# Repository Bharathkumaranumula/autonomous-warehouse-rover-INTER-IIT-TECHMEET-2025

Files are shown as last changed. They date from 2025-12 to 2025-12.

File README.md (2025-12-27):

# Autonomous Rover for Warehouse Rack Inventory Management

## About the Project
This project was developed as part of **Inter IIT Tech Meet 14.0** under the problem statement **“Autonomous Rover for Warehouse Rack Inventory Management.”**  
The objective was to design and build an autonomous wheeled robot capable of navigating warehouse aisles and performing **reliable vertical inventory scanning up to 2 meters**.

The system aims to replace slow, unsafe, and error-prone manual inventory audits with a compact, accurate, and scalable robotic solution suitable for modern warehouse environments.

---

## My Contribution
I was responsible for the **entire hardware design and implementation** of this project. My role covered the complete hardware lifecycle, including mechanical design, structural layout, drive system selection, Z-axis scissor lift design, power system architecture, safety mechanisms, and hardware integration.

I led the hardware development from problem understanding and calculations through CAD design, fabrication, assembly, and testing, ensuring the system met competition constraints and performed reliably during integrated operation.

---

## Problem Statement Summary
Modern warehouses face several challenges:
- Manual inventory audits take **10–15 minutes per rack**
- Human errors lead to **30–50% stock mismatches**
- Ladder-based high-rack inspections are unsafe
- Inventory data lacks real-time visibility

The robot must:
- Navigate narrow warehouse aisles autonomously
- Detect and align with storage racks
- Perform vertical scanning across multiple shelf levels (up to ~2 m)
- Reliably capture QR-based inventory data
- Operate safely within strict size and weight constraints

---

## Proposed Solution
The solution is a **compact autonomous differential-drive rover** equipped with a **centrally mounted multi-stage scissor lift** for vertical scanning.

Key system capabilities include:
- Autonomous indoor navigation
- Vertical scanning up to ~1.8–2.0 m
- High QR scanning accuracy
- Modular mechanical and electrical design
- Robust safety and fail-safe mechanisms

---

## System Overview
- Robot type: Autonomous wheeled mobile robot  
- Drive type: Differential drive (2 powered wheels + 2 ball casters)  
- Vertical actuation: Four-stage scissor lift  
- Maximum scanning height: ~1.8–2.0 m  
- Total system mass: ~20 kg  
- Footprint: 570 × 355 mm  
- Compute: NVIDIA Jetson AGX Xavier  
- Low-level control: ESP32  

---

## Hardware Architecture

### 1. Chassis and Structural Design
- Dimensions: **570 × 355 × 145 mm**
- Ground clearance: **25 mm**
- Total mass: **≈ 20 kg**
- Material: **6062 aluminium T-slot profiles (20 × 20 mm)**
- Closed-box frame topology for improved stiffness
- Low and centrally placed mass for anti-tip stability
- Modular mounting surfaces for rapid iteration

---

### 2. Locomotion System (X–Y Motion)
- Drive configuration: **2-wheel differential drive**
- Support: Front and rear metal ball casters
- Turning radius: **0 mm (on-the-spot rotation)**
- Drive wheel diameter: **100 mm**
- Wheel width: **25 mm**
- Motors: **RMCS 2012 DC motors**
  - Voltage: 18 V  
  - Gearbox: 1:25 planetary  
  - Rated torque: 39 kg·cm  
  - Encoders: ~1300 CPR at wheel  
- Direct-drive layout for minimal backlash
- Stability and torque validated with conservative acceleration limits

---

### 3. Z-Axis Scissor Lift Mechanism
- Mechanism: **Four-stage scissor lift**
- Actuation: Horizontally oriented lead screw
- Camera height range: **~320 mm to ~1780 mm**
- Usable vertical coverage: **~1800 mm**
- Shelf levels supported: **5 discrete heights**
- Vertical accuracy target: **±20 mm**
- Achieved repeatability: **~9–18 mm**
- Anti-sway achieved through symmetric geometry and tight-fit bearings
- Mechanical hard stops and limit switches for safety

---

### 4. Power System
- Three independent Li-Po batteries:
  - Jetson AGX Xavier
  - Drive motors
  - Z-axis motor
- 25C discharge capability
- Power Management Unit (PMU) for regulated distribution
- Electrical isolation between compute and motors
- Live battery monitoring and diagnostics

---

### 5. Control Electronics
- Microcontroller: **ESP32 DevKit-V1**
- Motor drivers: **Cytron MDD20A**
- Encoder-based closed-loop PID control
- UART communication between ESP32 and Jetson
- PCB designed with separate logic and power zones for reliability

---

### 6. Safety Systems
- Electronic kill switch (power cut-off)
- Physical emergency stop (E-stop)
- Z-axis limit switches and bump switch
- Firmware-level command clamping
- Software-triggered emergency stop on fault detection

---

## Hardware–Software Integration
- ESP32 handles real-time motor control and encoder feedback
- Jetson AGX Xavier handles perception, mapping, and planning
- ROS2 hardware interfaces synchronize:
  - X–Y motion
  - Z-axis positioning
  - Scanning tasks
- Closed-loop feedback ensures stable and repeatable operation

---

## Testing and Validation
Hardware validation included:
- Static load and structural stability tests
- Drive torque and acceleration verification
- Full-stroke Z-axis endurance testing
- Vertical positioning repeatability tests
- Integrated navigation + lift + scanning runs

### Key Results
- Vertical repeatability: **≤ 18 mm**
- Platform tilt at maximum lift: **≤ 1.3°**
- QR scanning success rate: **96% first pass, 100% with rescan**
- No jamming or over-current events observed

---

## Key Hardware Highlights
- Horizontally actuated scissor lift within base footprint
- Modular T-slot chassis acting as a mechanical backplane
- Differential drive optimized for stability and control simplicity
- COTS-heavy, serviceable, and student-replicable design
- Hardware decisions driven by safety and testability

---

## Documentation
Detailed mechanical design, calculations, CAD models, testing procedures, and validation results are available in the **attached technical report** provided with this repository.

---

## Acknowledgements
Developed as part of **Inter IIT Tech Meet 14.0** under the **Eternal** problem statement on warehouse automation.

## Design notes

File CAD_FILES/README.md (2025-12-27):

# CAD Files Folder

**Project:**Autonomous Rover for Warehouse Rack Inventory Management
**Type:** Robotic Lifting & Mobility System  
**File Format:** STEP (.step)

---

##  Overview

This is a robotic lifting and mobility system designed around a scissor mechanism mounted onto a mobile chassis. The system integrates vertical motion through a Z-axis actuator, real-time sensing through an Intel RealSense D455i camera, and wheel-based locomotion.

This repository contains the STEP files required to view, analyze, or manufacture the mechanical assembly.

---

##  File Structure & Component Manifest

Below is a detailed breakdown of the subsystems and their corresponding CAD files.

### 1. Main Assembly Structure
**File:** `MAIN_BODY.step`
* **Purpose:** The primary chassis and structural base for the complete mechanism.
* **Mounting Position:** Acts as the base foundation. All major components—including the scissor mechanism, drive motors, slider guides, and electronics—interface directly with this part.

### 2. Scissor Mechanism
**Files:** `FIXED_SCISSOR_MOUNTING_BOTTOM.step`
* **Purpose:** Lower mounting base for the scissor mechanism.
* **Mounting Position:** Rigidly attached to the main chassis; holds the bottom hinge points.

**Files:** `SCISSOR_MECHANISM_LINK-1.step` / `SCISSOR_MECHANISM_LINK-2.step`
* **Purpose:** The primary link arms forming the cross-bar structure of the scissor lift.
* **Mounting Position:** Assembled with pivot joints to form the extendable mechanical linkage.

**File:** `SCISSOR_MECHANISM_SLIDER_SLOT.step`
* **Purpose:** Linear guide slot used to guide the motion of the scissor pivot.
* **Mounting Position:** Attached to the chassis or slider platform.

### 3. Slider and Support System
**Files:** `SLIDER_MOUNT_TYPE_1.step` / `SLIDER_MOUNT_TYPE_2.step`
* **Purpose:** Slider support assemblies ensuring smooth linear travel.
* **Mounting Position:** Located along the slider slot and support rails.

### 4. Actuation and Mobility
**File:** `Z_AXIS_ACTUATIOR_MOTOR_MOUNT.step`
* **Purpose:** Motor bracket for the Z-axis actuator (leadscrew or linear actuator).
* **Mounting Position:** Connected to the chassis, aligned with the lift’s thrust axis.

**File:** `WHEEL_MOTOR_SUPPORT_MOUNT.step`
* **Purpose:** Housing mount for the drive motors controlling robot locomotion.
* **Mounting Position:** Located on the lower-side faces of the chassis.

### 5. Sensing and Vision
**File:** `CAMERA_MOUNT.step`
* **Purpose:** Dedicated mount for the **Intel RealSense D455i** depth camera.
* **Mounting Position:** Placed behind the main actuator or rear side of the motor assembly, facing forward. Used for SLAM, mapping, and perception.

---

##  System Summary

| Subsystem | Components | Functional Purpose |
| :--- | :--- | :--- |
| **Chassis** | `MAIN_BODY` | Structural base and interface for all modules |
| **Lifting System** | Links + Slider components | Vertical movement (Scissor Lift) |
| **Actuator** | Z-axis motor mount | Power transmission for lift |
| **Drive** | Wheel motor support mounts | Horizontal mobility |
| **Vision** | Camera mount | Environment perception & navigation |

---

##  Usage
These files are provided in **.STEP** format, which is widely supported by standard CAD software including:
* SolidWorks
* Autodesk Fusion 360
* FreeCAD
* Onshape

To view the full assembly, import `MAIN_BODY.step` first, followed by the sub-components using the mounting positions described above.

---
*Documentation generated for the ETERNAL CAD Project.*

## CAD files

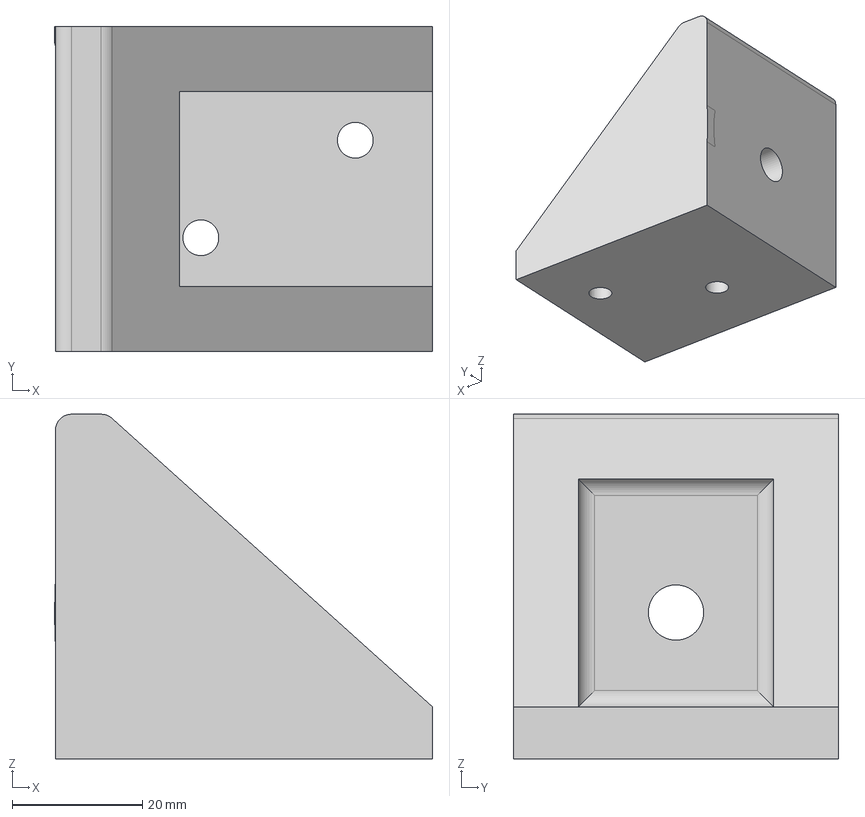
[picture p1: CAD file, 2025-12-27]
CAD_FILES/Z-axis/SLIDER_MOUNT_TYPE_2.step
58.1 x 50.0 x 53.0 mm

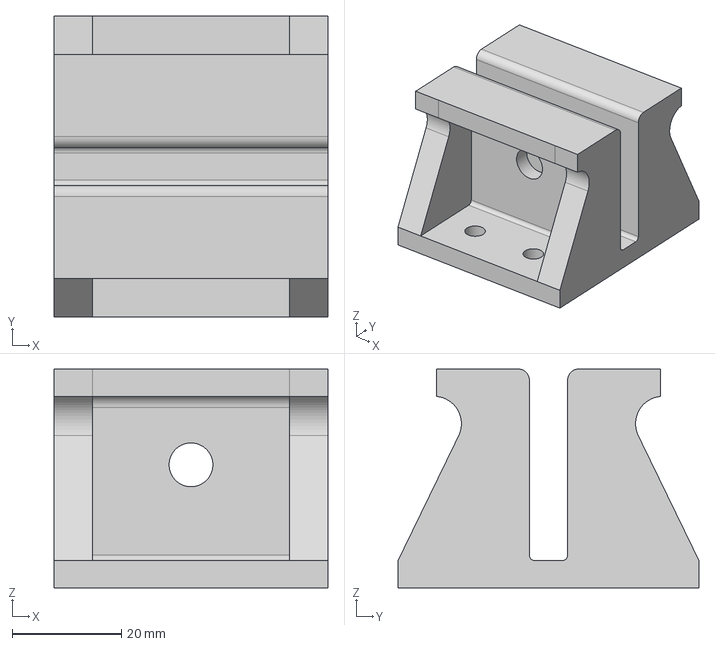
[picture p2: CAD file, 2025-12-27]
CAD_FILES/Z-axis/FIXED_SCISSOR_MOUNTING_BOTTOM.step
50.0 x 55.0 x 40.0 mm

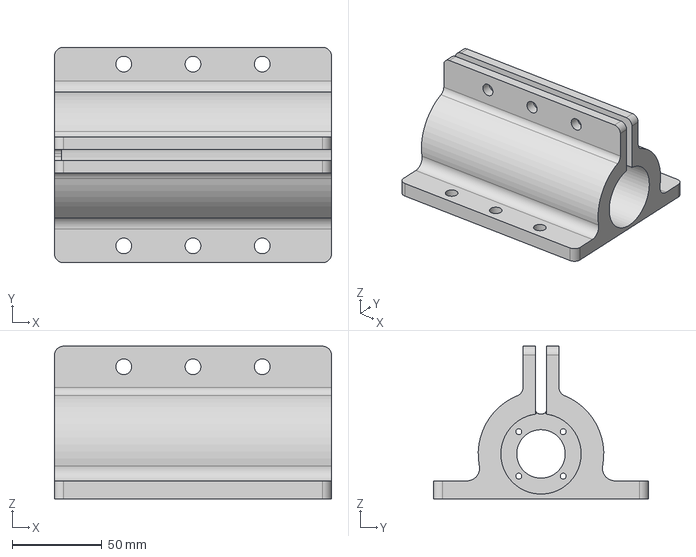
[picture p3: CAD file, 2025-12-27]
CAD_FILES/Z-axis/Z_AXIS_ACTUATIOR_MOTOR_MOUNT.step
154.3 x 120.0 x 85.0 mm

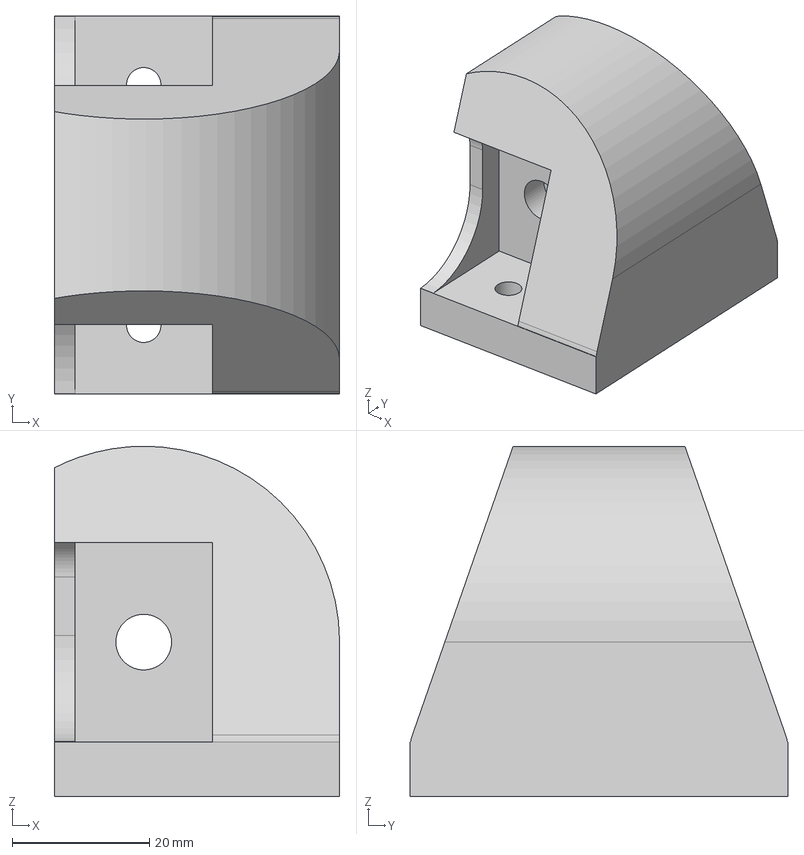
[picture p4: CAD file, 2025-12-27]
CAD_FILES/Z-axis/SLIDER_MOUNT_TYPE_1.step
41.5 x 55.0 x 51.0 mm

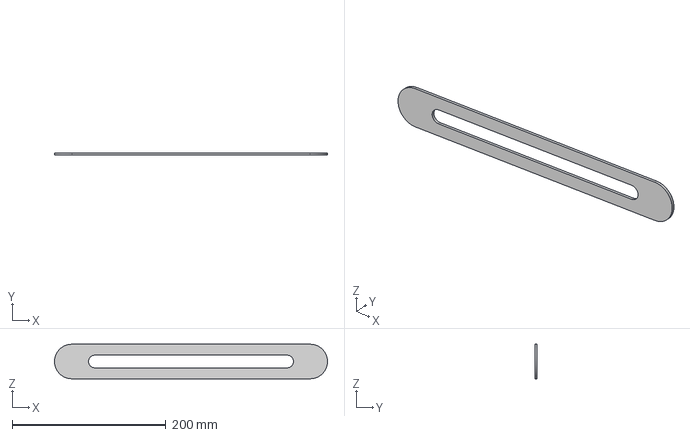
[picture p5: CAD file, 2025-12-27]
CAD_FILES/Z-axis/SCISSOR_MECHANISM_SLIDER_SLOT.step
355.0 x 3.00 x 45.0 mm

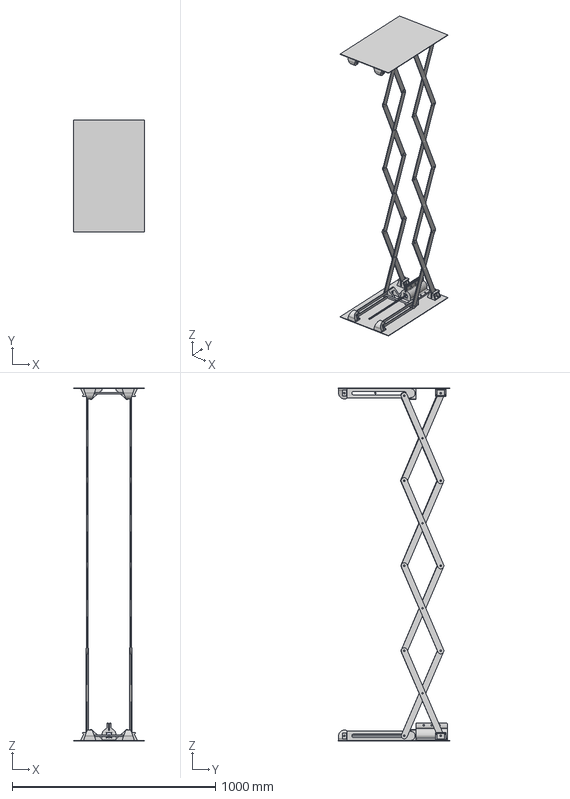
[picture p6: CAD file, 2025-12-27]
CAD_FILES/Z-axis/FINAL_SCISSOR.step
350.0 x 550.0 x 1735.9 mm
m x 2
SLOT x 2
MOUNT2_FINAL x 2
single_side_mount x 2
m v1(Mirror) x 2
SLOT v1(Mirror) x 2
MOUNT2_FINAL v2(Mirror) x 2
Component3(Mirror) x 2
single_side_mount v1(Mirror) x 2
LINK
LINK_1
LINK_2
LINK_3
LINK v2(Mirror)
LINK v2(Mirror)_1
LINK v2(Mirror)_2
LINK v2(Mirror)_3
LINK_4 x 6
LINK v2(Mirror) (1) x 6
Holder

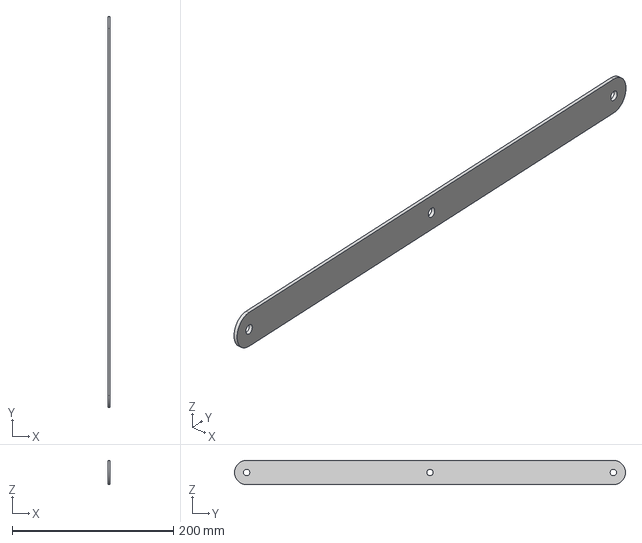
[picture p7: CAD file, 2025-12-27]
CAD_FILES/Z-axis/SCISSOR_MECHANISM_LINK-1.step
3.00 x 485.0 x 30.0 mm

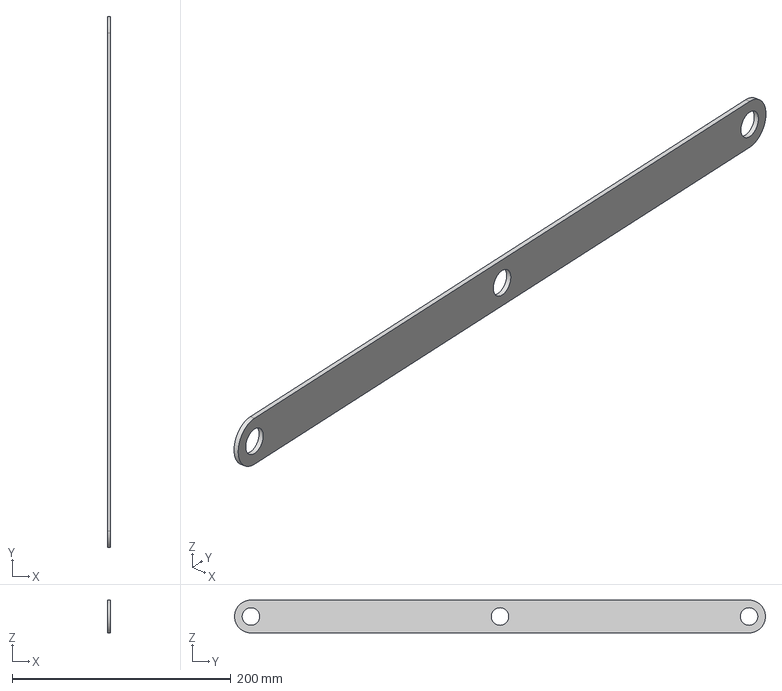
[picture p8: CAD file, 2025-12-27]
CAD_FILES/Z-axis/SCISSOR_MECHANISM_LINK-2.step
3.00 x 485.0 x 30.0 mm
